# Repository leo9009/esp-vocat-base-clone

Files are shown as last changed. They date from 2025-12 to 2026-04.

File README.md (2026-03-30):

# ESP-VoCat Smart Rotating Base

English | [简体中文](README_CN.md)

## Project Overview

The ESP-VoCat rotating base is a smart rotating platform designed specifically for the [**ESP-VoCat development kit**](https://docs.espressif.com/projects/esp-dev-kits/zh_CN/latest/esp32s3/esp-vocat/user_guide_v1.2.html), tailored for toys, smart speakers, smart hubs, and other products requiring large language model voice interaction capabilities. The device uses the ESP32-C61-WROOM-1 module, supports USB Type-C power supply, and can power the ESP-VoCat main unit through a magnetic interface.

This project implements **high-precision stepper motor control, magnetic slide switch event detection, CSI sensing capabilities**, and stable **UART communication** as core functions. It can automatically adjust direction based on ESP-VoCat's **Sound Source Localization** results, enabling intelligent rotation toward sound sources. By combining motion control with sound source perception, it provides a more **natural and immersive** human-computer interaction experience.

## Key Features

- **Precise Angle Control** - High-precision rotational positioning based on stepper motor
- **Magnetic Slide Switch** - Multiple sensor support with automatic calibration
- **Rich Preset Actions** - Natural movements like shake head, look around, beat rhythm
- **Auto Homing** - Automatic zero position finding and calibration on startup
- **Bidirectional Communication** - Real-time data exchange between controller and base
- **Data Persistence** - Calibration data saved, survives power loss

## Project Structure

```
esp-vocat-base/
├── hardware/                    # Hardware design files
│   ├── schematics/              # Schematics
│   └── pcb/                     # PCB design files
├── software/                    # Firmware code
│   ├── common_components/       # Shared components for all examples
│   │   ├── stepper_motor/               # Stepper motor control
│   │   ├── magnetic_slide_switch/       # Magnetic switch (profile-based)
│   │   ├── control_serial/              # Serial communication
│   │   └── BMM150_SensorAPI/            # Sensor driver
│   ├── esp_vocat_rotating_base/                         # Base firmware
│   ├── esp_vocat_rotating_base_bell_event_detection/    # Bell slider event demo
│   ├── esp_vocat_rotating_base_iphone_detection/        # iPhone detection demo
│   └── esp_vocat_rotating_base_magnetic_accessory_detection/ # Accessory detection demo
├── README.md                    # English documentation
└── README_CN.md                 # Chinese documentation
```

## Example Projects

To avoid frequent branch switching, `software/` includes 4 independently buildable example projects:

- `esp_vocat_rotating_base`  
  Base firmware with standard capabilities: stepper actions, core magnetic slider events, UART communication, calibration, and status sync.

- `esp_vocat_rotating_base_bell_event_detection`  
  Bell slider event detection demo, focused on bell-related magnetic slider event logic.

- `esp_vocat_rotating_base_iphone_detection`  
  iPhone detection demo, focused on phone approach/leave and under-base related detection events.

- `esp_vocat_rotating_base_magnetic_accessory_detection`  
  Magnetic accessory detection demo, focused on accessory magnetic event recognition (e.g. fish/ice-cream/donut style accessories).

All projects share common components under `software/common_components/`.  
The `magnetic_slide_switch` component selects different profiles per project to keep event definitions and detection behavior compatible.

## **Feature Showcase**

[**Video Showcase**](https://www.bilibili.com/video/BV19gSEBwEoj/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)

The ESP-VoCat base uses Espressif's **ESP32-C61-WROOM-1(N8R2)** module and communicates with the ESP-VoCat main unit via a custom UART protocol. In terms of mechanical structure, the base is equipped with a 24BYJ48 stepper motor, enabling sound source localization and various predefined rotation actions to enhance interaction experience.
Additionally, the ESP-VoCat base features a magnetic slide switch that unlocks more interactive experiences.

### **Sound Source Localization**
ESP-VoCat supports sound source localization, capable of real-time detection of sound direction and position in the environment. The system collects sound signals through a microphone array and analyzes sound intensity, phase, and other information to determine the azimuth of the sound source. Combined with an ultra-quiet stepper motor-based rotating base, it enables intelligent interaction facing the sound source.

Sound Source Localization

### **Multiple Preset Actions**
The rotating base supports various predefined actions:

- **Shake Head Action**
The shake head action makes the base gently swing the companion left and right, simulating a cat's curious or subtle gesture.

Shake Head

- **Curious Look Around**
The curious look around action makes the base move the companion's head left and right, with small random offsets, simulating a **cat naturally observing its environment**.

Look Around

- **Beat Rhythm**
The beat rhythm action enables ESP-VoCat to swing its head left and right according to **drum beats** in external music, creating an **interactive effect** synchronized with music.

Beat Following

- **Gentle Nuzzle**
The gentle nuzzle simulates a cat's tender nuzzling action: the base slowly turns left and returns to center, repeating several times. The motion is smooth and natural, with each pause enhancing the **tactile feel** and **gentleness**.

Nuzzle

  **Notes:**
  All actions are **parametrically controllable**, facilitating integration with large models like **Doubao** and **Xiaozhi**.
  To better execute actions, the base's motor control features:
  - **Precise Angle Control:** Supports rotation at any angle with precision up to 0.1 degrees, serving sound source localization
  - **Smooth Acceleration/Deceleration:** Uses acceleration algorithms for natural and smooth rotation
  - **Auto Homing Calibration:** 
  Since the ESP-VoCat rotating base is driven by a stepper motor, it has no angle feedback. Therefore, the base performs zero position calibration at startup:
   1. After power-on, the motor automatically rotates left to find the limit switch
   2. After touching the limit switch, the motor rotates right 95° to the center position
   3. After calibration is complete, the motor powers off

### **Magnetic Slide Switch Interaction Control**
The ESP-VoCat base implements multiple interaction controls through a **magnetic** slide switch. Different slider positions change the magnetic field strength around the magnetometer. The base identifies slider actions by monitoring these magnetic field changes in real-time. When position changes are detected, the base reports corresponding events to ESP-VoCat via serial port, enabling rich and intuitive interactive experiences.

Supports 9 types of magnetic slide switch event detection:
   - Slider moved from up to down (`SLIDE_DOWN`): Slider is moved from the upper position to the lower position.
   - Slider moved from down to up (`SLIDE_UP`): Slider is moved from the lower position to the upper position.
   - Slider removed from up position (`REMOVE_FROM_UP`): Slider is removed from the upper position.
   - Slider removed from down position (`REMOVE_FROM_DOWN`): Slider is removed from the lower position.
   - Slider placed at up position (`PLACE_FROM_UP`): Slider is placed into the upper position.
   - Slider placed at down position (`PLACE_FROM_DOWN`): Slider is placed into the lower position.
   - Single click action (`SINGLE_CLICK`): A single-click action is detected when the slider stays at the lower position.
   - Fish feeding event (`FISH_ATTACHED`): Fish accessory is detected as attached.
   - Pairing mode (`PAIRING`): Two ESP-VoCat devices are face-to-face and pairing condition is detected.

Magnetic Switch

Magnetic slide switch control supports **multiple sensors**:
 - BMM150 3-axis magnetometer
 - QMC6309 3-axis magnetometer
 - Linear Hall sensor

  **Notes:**
  1. **Choose one** of the above sensors; **BMM150** is selected by default. When using a linear Hall sensor, **only** slider up/down sliding (SLIDE_UP / SLIDE_DOWN) event detection is supported!
  2. Before first use, **fully automatic calibration** of the magnetic slide switch is required to adapt to the magnetic environment, recording magnetic field strength baseline values for three states: **up / down / removed**:
     - System automatically detects three stable positions (keep still for about 500ms each position)
     - No manual prompts required, system automatically judges position differences
     - Calibration data persistently stored via NVS Flash, survives power loss
     - During use, recalibration can be triggered by sending a serial command from ESP-VoCat or long-pressing the base's Boot button

Based on magnetometer detection results combined with intelligent motion determination algorithms, the base can recognize nine types of actions and events.

### **CSI Sensing Capability**
The companion can perceive environmental changes through Wi-Fi CSI (Channel State Information), enabling action triggering or environmental interaction.
- **Movement Detection** 
By obtaining CSI information from routers through the companion, human movement throughout the entire space can be detected, enabling human movement detection and data statistics.

- **Near-field Perception** 
Through packet exchange between the companion and base, Wi-Fi transmission paths can be controlled to achieve small-range, high-precision detection. For example, when a human finger is detected approaching, the base can automatically adjust posture or execute preset actions, enabling smarter interactive experiences.

CSI Sensing

### **Serial Communication**
The ESP-VoCat rotating base communicates with ESP-VoCat via **UART protocol**.

- **Command Types**:
    - Angle control command (CMD_BASE_ANGLE_CONTROL)
    - Preset action control command (CMD_BASE_ACTION_CONTROL)
    - Preset action completion notification (CMD_ACTION_COMPLETE)
    - Magnetic switch event report (CMD_MAGNETIC_SWITCH_EVENT)
    - Magnetic data calibration progress sync (MAG_SWITCH_CALIB_*)

Note: Currently only the above basic command types are available; CSI-related commands will be added later.
    
-  **Data Frame Format**:
    -   `AA 55 [LEN_H] [LEN_L] [CMD] [DATA...] [CHECKSUM]` 
-  **Verification Mechanism**:
    - **Frame header** verification
    - **Checksum** verification

[**Detailed command data frame example**](software/esp_vocat_rotating_base/README.md)

## **Hardware Requirements**

### **Main Control Chip**
- **ESP32-C61-WROOM-1** or **ESP32-C61-WROOM-1U** module

ESP32-C61-WROOM-1 is used by default

- [**Hardware Open Source**](https://oshwhub.com/esp-college/esp-echoear-base)

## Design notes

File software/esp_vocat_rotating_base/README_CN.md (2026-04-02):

# ESP-VoCat-Base: 喵伴旋转底座

**中文** | [English](README.md)

## 项目简介

该项目工程是乐鑫"喵伴"智能交互设备的旋转底座固件，基于 ESP32-C61 芯片开发。该项目实现了步进电机精确控制、磁吸滑动开关检测、串口通信等功能，为智能设备提供生动的交互动作和灵敏的输入检测。

## 主要特性

### 步进电机控制
- **多种预定义动作**：
  - 摇头动作（固定幅度/渐变递减）
  - 左顾右盼观察动作
  - 猫咪蹭手动作
  - 跟随鼓点左右摆头动作

所有动作都可参数化调控，便于对接豆包、小智等大模型。
- **精确角度控制**：支持任意角度旋转，精度可达 0.1 度
- **平滑加减速**：采用加减速算法，运动更自然流畅
- **半步驱动模式**：提高精度 2 倍，运动更平滑
- **自动归位校准**：启动时通过限位开关自动回零

### 磁吸滑动开关
- **多种传感器支持**：
  - BMM150 三轴地磁传感器
  - QMC6309 三轴地磁传感器
  - 线性霍尔传感器

以上三种传感器三选一即可，默认选择 BMM150。
- **丰富的事件检测**：
  - 滑块上下滑动（SLIDE_UP / SLIDE_DOWN）
  - 从上/下位置取下（REMOVE_FROM_UP / REMOVE_FROM_DOWN）
  - 从上/下位置放回（PLACE_FROM_UP / PLACE_FROM_DOWN）
  - 单击事件（SINGLE_CLICK）：基于 mag_x 轴数据变化检测，结合 mag_x 和 mag_y 关系判断，防止滑动误触发
  - 喂鱼事件（FISH_ATTACHED）：检测小鱼从上位置放置的特定磁场变化
  - 配对模式（PAIRING）：检测长时间处于特定磁场状态
- **智能校准功能**：
  - 全自动校准流程：无需手动操作提示，系统自动检测三个稳定位置
  - 快速稳定检测：500ms 稳定时间（BMM150）/ 2000ms（QMC6309）
  - 智能位置识别：自动判断位置差异，避免重复记录
  - 校准数据持久化存储（NVS Flash）
  - 支持串口命令触发重新校准
  - 支持长按 Boot 键触发重新校准
  - 自动适配不同磁场环境

### 串口通信
- **UART 协议通信**：与 ESP-VoCat 进行数据通信
- **命令类型**：
  - 角度控制命令（CMD_BASE_ANGLE_CONTROL）
  - 预设动作控制命令（CMD_BASE_ACTION_CONTROL）
  - 预设动作完成通知（CMD_ACTION_COMPLETE）
  - 磁吸开关事件上报（CMD_MAGNETIC_SWITCH_EVENT）
  - 校准进度通知（MAG_SWITCH_CALIB_*）
- **数据帧格式**：`AA 55 [LEN_H] [LEN_L] [CMD] [DATA...] [CHECKSUM]`
- **校验机制**：支持**帧头**校验、**校验和**验证

## 硬件要求

### 主控芯片
- **ESP32-C61-WROOM-1** 或 **ESP32-C61-WROOM-1U** 模组

默认使用 ESP32-C61-WROOM-1

### 外设连接与引脚分配

#### 步进电机（28BYJ-48 + ULN2003 驱动 IC）
- IN1 → GPIO28
- IN2 → GPIO27
- IN3 → GPIO26
- IN4 → GPIO25

#### 磁力计传感器（I2C）
- SCL → GPIO3
- SDA → GPIO2
- 支持 BMM150（I2C 地址：0x10）
- 支持 QMC6309（I2C 地址：0x7C）

#### 线性霍尔传感器（ADC）
- ADC_PIN → GPIO5（ADC_CHANNEL_3）

#### 转台回零校准限位开关
- 回零校准限位开关检测引脚 → GPIO1（低电平有效）

#### BOOT 按键
- BOOT 按键 → GPIO9（低电平有效）

默认用于长按进行磁吸滑动开关校准。

#### UART 通信
- TXD → GPIO29
- RXD → GPIO8
- 波特率：115200

## 软件架构

### 主要组件

#### 1. stepper_motor（步进电机控制）
- 实现半步驱动控制算法
- 提供加减速曲线
- 封装多种预定义动作
- 支持精确角度旋转

#### 2. magnetic_slide_switch（磁吸滑动开关）
- 滑动窗口滤波算法（mag_z 轴）
- 状态机实现事件检测
- 单击检测（基于 mag_x 轴变化 + mag_x/mag_y 关系判断）
- 喂鱼事件检测（特定磁场增量范围）
- 配对模式检测（两个 ESP-VoCat 面对面靠近，用于配对联网）
- 全自动校准流程（时间基准 + 智能位置识别）
- 校准数据 NVS 持久化存储

#### 3. control_serial（串口通信）
- UART 收发任务
- 协议帧解析
- 命令分发处理
- 事件上报

#### 4. BMM150_SensorAPI（传感器驱动）
- BMM150 官方 API 适配
- I2C 总线封装

### 任务结构
```
app_main
├── base_calibration_task          // 底座角度校准任务（启动时，完成后销毁）
├── uart_cmd_receive_task          // UART 命令接收任务
├── magnetic_detect_task           // 磁吸附状态周期上报任务
├── magnetometer_calibration_task  // 磁吸开关自动校准任务
└── slide_switch_event_detect_task // 磁吸滑动开关事件检测任务
```

## 快速开始

### 环境准备

1. **ESP-IDF 版本**

- ESP-IDF release/v5.5(v5.5-445-g1191f4c4f91-dirty)

### 配置项目

使用 `idf.py menuconfig` 选择磁吸滑动开关所用的传感器：

 `Component config → Magnetic Slide Switch → Sensor Type`

选择传感器类型：BMM150 / QMC6309 / Linear Hall Sensor

### 编译烧录

```bash
# 编译项目
idf.py build
# 烧录固件
idf.py flash
# 查看日志
idf.py monitor
```

## 使用说明

### 首次启动

1. **底座角度校准**：
   - 上电后，电机会自动向左旋转寻找限位开关
   - 触碰到限位开关后，电机会向右旋转 95° 到中心位置
   - 校准完成后，电机断电

2. **磁吸开关自动校准**（如果是首次使用）：
   - 系统自动检测第一个稳定位置（保持滑块静止约 500ms）
   - 系统记录第一个位置后，提示：`First position calibrated`
   - 将滑块移动到第二个不同位置（上/下/拿掉），系统自动检测稳定
   - 系统记录第二个位置后，发送 `0x12` 给 ESP-VoCat，通知第二个位置校准完成
   - 将滑块移动到第三个不同位置，系统自动检测稳定
   - 系统记录第三个位置后，自动按磁场强度排序分配到 REMOVED/UP/DOWN
   - 校准完成后发送 `0x13` 给 ESP-VoCat，通知校准完毕
   - 校准数据自动保存到 Flash，下次启动自动加载
   
   **注意**：
   - 每个位置需要保持静止，等待系统自动检测稳定（约 500ms）
   - 三个位置的磁场差异需大于 100（系统自动判断）
   - 移动过程中数据变化正常，系统会自动等待稳定后记录

### 重新校准

**方法 1：长按 Boot 按键**
- 长按 GPIO9 的 Boot 按键（约 1.5 秒）
- 系统自动进入重新校准模式

**方法 2：串口命令**
- 发送命令：`AA 55 00 03 03 00 10 13`
- 系统收到命令后进入重新校准模式

### 串口命令

#### 1. 磁吸通知命令（0x00）
`
AA 55 00 03 00 00 01 01
`

底座会周期性发送该命令，ESP-VoCat 在被磁吸连接后若成功接收到此命令，即可确认已与底座建立连接，并开始播放连接动画。

#### 2. 角度控制命令（0x01）
**格式**：`AA 55 00 03 01 [ANGLE_H] [ANGLE_L] [CHECKSUM]`

**示例**：旋转到 45°
```
AA 55 00 03 01 00 2D 2E
```
- `00 2D` = 45（十进制）
- `2E` = `01 + 00 + 2D`（校验和）

#### 3. 动作控制命令（0x02）
**格式**：`AA 55 00 03 02 00 [ACTION] [CHECKSUM]`

**动作码**：
- `0x01`：摇头（SHAKE_HEAD）
- `0x02`：左顾右盼（LOOK_AROUND）
- `0x03`：跟随鼓点-鼓类（BEAT_SWING_DRUM）
- `0x04`：猫咪蹭手（CAT_NUZZLE）
- `0x05`：跟随鼓点-其他乐器（BEAT_SWING_OTHER）

**示例**：执行左顾右盼动作
```
AA 55 00 03 02 00 02 04
```

#### 4. 磁吸开关事件上报（0x03）
**格式**：`AA 55 00 03 03 00 [EVENT] [CHECKSUM]`

**事件码**：
- `0x01`：滑块向下滑动（SLIDE_DOWN）
- `0x02`：滑块向上滑动（SLIDE_UP）
- `0x03`：从上面拿下（REMOVE_FROM_UP）
- `0x04`：从下面拿下（REMOVE_FROM_DOWN）
- `0x05`：从上面放回（PLACE_FROM_UP）
- `0x06`：从下面放回（PLACE_FROM_DOWN）
- `0x07`：单击事件（SINGLE_CLICK）
- `0x08`：喂鱼事件（FISH_ATTACHED）- 小鱼从上位置放置时触发
- `0x09`：配对模式（PAIRING）- 长时间处于特定磁场状态
- `0x10`：启动数据校准程序
- `0x11`：校准开始通知
- `0x12`：第二个位置校准完成（头部收到后语音提示第三步）
- `0x13`：校准完成

#### 5. 动作完成通知（0x02）
**格式**：`AA 55 00 03 02 00 10 12`

- 底座在执行完任意特定动作后自动发送
- 头部可根据此命令同步状态

## 步进电机动作详解

### 1. stepper_shake_head（摇头）
```c
stepper_shake_head(float amplitude, int cycles, int speed_us);
```
- `amplitude`：摆动幅度（度）
- `cycles`：摆动次数
- `speed_us`：速度（微秒/步）

### 2. stepper_shake_head_decay（渐变摇头）
```c
stepper_shake_head_decay(float initial_amplitude, float decay_rate, int speed_us);
```
- `initial_amplitude`：初始幅度（度）
- `decay_rate`：衰减系数（0.0-1.0，如 0.8 表示每次衰减 20%）
- `speed_us`：速度（微秒/步）

### 3. stepper_look_around（左顾右盼）
```c
stepper_look_around(float left_angle, float right_angle, float scan_angle, 
                    int pause_ms, int large_speed_us, int small_speed_us);
```
- `left_angle`：左侧最大角度
- `right_angle`：右侧最大角度
- `scan_angle`：小幅度扫视角度
- `pause_ms`：每次转动后的停顿时间
- `large_speed_us`：大幅度转动速度
- `small_speed_us`：小幅度扫视速度

### 4. stepper_cat_nuzzle（猫咪蹭手）
```c
stepper_cat_nuzzle(float angle, int cycles, int speed_us);
```
- `angle`：蹭动幅度（度）
- `cycles`：蹭动次数
- `speed_us`：速度（微秒/步）

### 5. stepper_beat_swing（跟随鼓点）
```c
stepper_beat_swing(float angle, int speed_us);
```
- `angle`：摆动角度（度）
- `speed_us`：速度（微秒/步）
- **智能摆动逻辑**：
  - 同类乐器连续触发 → 向另一侧摆动 15 度

## 磁吸开关校准原理

### 自动校准流程状态机

```
CALIBRATION_DETECTING_FIRST      // 自动检测第一个稳定位置
         ↓                       // 数据稳定 500ms 后自动记录
CALIBRATION_WAITING_CHANGE_1     // 等待数据变化（用户移动滑块）
         ↓                       // 检测到变化量 > 100
CALIBRATION_DETECTING_SECOND     // 自动检测第二个稳定位置
         ↓                       // 数据稳定 500ms 后自动记录
         |                       // （发送 0x12 通知头部）
CALIBRATION_WAITING_CHANGE_2     // 等待数据变化（用户移动滑块）
         ↓                       // 检测到变化量 > 100
CALIBRATION_DETECTING_THIRD      // 自动检测第三个稳定位置
         ↓                       // 数据稳定 500ms 后自动记录
CALIBRATION_COMPLETED            // 自动排序并保存到 Flash
                                 // （发送 0x13 通知头部）
```

### 关键技术点

1. **滑动窗口滤波**：5 点滑动平均，降低噪声干扰
2. **时间基准稳定性检测**：
   - 使用系统时钟（FreeRTOS Tick）精确计时
   - 数据变化小于 10 个单位视为稳定
   - BMM150：连续稳定 500ms 后记录
   - QMC6309：连续稳定 500ms 后记录
3. **智能位置识别**：
   - 自动检测数据变化量（阈值 100）
   - 新位置必须与已记录位置差异明显
   - 防止重复记录同一位置
4. **自动排序分配**：
   - 按磁场强度从小到大排序
   - 最小值 → REMOVED（拿掉）
   - 中间值 → UP（上位置）
   - 最大值 → DOWN（下位置）
5. **NVS 持久化**：校准数据保存到 Flash，掉电不丢失
6. **无需手动提示**：全程自动检测，用户只需按顺序移动滑块并保持静止

### 磁场值参考范围（BMM150）
- **REMOVED**（拿掉）：~700-800（默认 709）
- **UP**（上位置）：~1300-1400（默认 1383）
- **DOWN**（下位置）：~2000-2100（默认 2047）
- **FISH_ATTACHED**（喂鱼）：REMOVED + 150~200

*注：实际值因磁铁强度和安装位置而异，自动校准会根据实际磁场分配位置*

### 事件检测特点

**单击事件检测**：
- 基于 mag_x 轴数据变化（drop/rise threshold: 100）
- 结合 mag_x 和 mag_y 大小关系判断滑块位置
- 仅在滑块处于 DOWN 位置时检测（mag_x > mag_y）
- 持续时间过滤：< 300ms 为有效单击
- 防止快速滑动误触发

**喂鱼事件检测**：
- 仅在 REMOVED 位置后检测
- 磁场增量在 150-200 范围内
- 区别于 PLACE_FROM_UP（增量更大，接近 UP_CENTER）

**配对模式检测**：
- REMOVED 位置后磁场继续下降
- 下降量 > 100（BMM150）/ 150（QMC6309）
- 稳定保持该状态

### 常见问题

**Q1：电机抖动或不转**
- 检查供电是否充足（至少 5V 1A）
- 检查接线是否正确
- 尝试降低速度（增大 `speed_us` 参数）

**Q2：磁吸开关校准失败**
- 确保传感器 I2C 连接正常
- 检查传感器类型配置是否匹配
- 每个位置需保持静止至少 500ms（BMM150）/ 2000ms（QMC6309）
- 三个位置的磁场差异需大于 100，确保位置明确不同
- 如移动过快导致检测不到变化，可稍等片刻让系统重新检测

**Q3：单击事件误触发或不触发**
- 误触发：可能是快速滑动导致，系统已通过 mag_x/mag_y 关系优化
- 不触发：确保滑块在 DOWN 位置（mag_x > mag_y），单击动作要明确快速
- 单击时长应小于 300ms，过慢会被识别为滑动

**Q4：串口通信异常**
- 检查波特率是否为 115200
- 确认 TX/RX 接线是否正确
- 检查校验和是否计算正确

**Q5：首次上电电机旋转方向错误**
- 检查限位开关安装位置
- 调整 `base_calibration_task` 中的旋转角度

## 性能参数

- **角度控制精度**：±0.5°
- **最快旋转速度**：600 μs/步（约 200°/秒）
- **磁吸开关响应时间**：< 50ms
- **磁吸开关采样率**：100 Hz（BMM150，10ms 周期）/ 500 Hz（QMC6309，2ms 周期）
- **校准稳定检测时间**：500ms（BMM150）/ 2000ms（QMC6309）
- **单击检测时间窗口**：< 300ms（BMM150）/ < 250ms（QMC6309）
- **串口通信速率**：115200 bps
- **内存占用**：~80KB RAM，~200KB Flash

## 版本历史

### v1.1.0
- **新增功能**：
  - 喂鱼事件检测（FISH_ATTACHED）
  - 配对模式检测（PAIRING）
- **优化改进**：
  - 磁吸数据校准流程全自动化（无需手动提示）
  - 时间基准稳定性检测（FreeRTOS Tick 计时）
  - 单击事件检测优化：基于 mag_x 轴 + mag_x/mag_y 关系判断
  - 防止快速滑动误触发单击事件
  - 校准稳定时间优化：BMM150 降至 500ms
  - 智能位置识别（自动判断位置差异）

### v1.0.0
- 步进电机基础控制
- 多种预定义动作
- 磁吸滑动开关事件检测
- 自动校准功能
- NVS 数据持久化
- 串口通信协议
- 智能跟随鼓点算法
- 长按 Boot 键重新校准
- 校准过程串口通信

## 许可证

本项目遵循 GPL 3.0 许可证。

---

**注意**：本项目为乐鑫"喵伴"智能设备配套固件，仅供学习和参考使用。

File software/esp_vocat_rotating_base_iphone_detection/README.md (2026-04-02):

# ESP-ESP-VoCat Rotating Base

[中文](README_CN.md) | **English**

## Project Introduction

This project is the firmware for the rotating base of Espressif's ESP-VoCat intelligent interactive device, developed based on the ESP32-C61 chip. The project implements precise stepper motor control, magnetic slide switch detection, UART communication, and other features, providing vivid interactive actions and sensitive input detection for smart devices.

## Main Features

### Stepper Motor Control
- **Multiple Predefined Actions**:
  - Head shaking action (fixed amplitude/gradual decay)
  - Look around observation action
  - Cat nuzzle action
  - Beat swing action following rhythm

All actions are parameterizable for easy integration with LLMs like Doubao and Xiaozhi.
- **Precise Angle Control**: Supports arbitrary angle rotation with precision up to 0.1 degrees
- **Smooth Acceleration/Deceleration**: Uses acceleration/deceleration algorithms for more natural and fluid motion
- **Half-Step Drive Mode**: Doubles precision for smoother movement
- **Auto Homing Calibration**: Automatically returns to zero position via limit switch on startup

### Magnetic Slide Switch
- **Multiple Sensor Support**:
  - BMM150 3-axis magnetometer
  - QMC6309 3-axis magnetometer
  - Linear Hall sensor

Choose one of the above three sensors, BMM150 is selected by default.
- **Rich Event Detection**:
  - Slider up/down sliding (SLIDE_UP / SLIDE_DOWN)
  - Remove from up/down position (REMOVE_FROM_UP / REMOVE_FROM_DOWN)
  - Place back from up/down position (PLACE_FROM_UP / PLACE_FROM_DOWN)
  - Single click event (SINGLE_CLICK): Detected based on mag_x axis data changes, combined with mag_x and mag_y relationship judgment to prevent false triggers from sliding
  - Fish feeding event (FISH_ATTACHED): Detects specific magnetic field changes when small fish is placed from up position
  - Pairing mode (PAIRING): Two ESP-VoCat devices face-to-face for pairing and networking
- **Smart Calibration Function**:
  - Fully automatic calibration process: No manual prompts required, system automatically detects three stable positions
  - Fast stability detection: 500ms stability time for both BMM150 and QMC6309
  - Intelligent position recognition: Automatically judges position differences to avoid duplicate recording
  - Calibration data persistent storage (NVS Flash)
  - Support UART command triggered recalibration
  - Support long press Boot button triggered recalibration
  - Auto-adapt to different magnetic field environments

### UART Communication
- **UART Protocol Communication**: Data communication with ESP-VoCat
- **Command Types**:
  - Angle control command (CMD_BASE_ANGLE_CONTROL)
  - Preset action control command (CMD_BASE_ACTION_CONTROL)
  - Preset action completion notification (CMD_ACTION_COMPLETE)
  - Magnetic switch event reporting (CMD_MAGNETIC_SWITCH_EVENT)
  - Calibration progress notification (MAG_SWITCH_CALIB_*)
- **Data Frame Format**: `AA 55 [LEN_H] [LEN_L] [CMD] [DATA...] [CHECKSUM]`
- **Verification Mechanism**: Supports **frame header** verification and **checksum** validation

## Hardware Requirements

### Main Control Chip
- **ESP32-C61-WROOM-1** or **ESP32-C61-WROOM-1U** module

ESP32-C61-WROOM-1 is used by default

### Peripheral Connection and Pin Assignment

#### Stepper Motor (28BYJ-48 + ULN2003 Driver IC)
- IN1 → GPIO28
- IN2 → GPIO27
- IN3 → GPIO26
- IN4 → GPIO25

#### Magnetometer Sensor (I2C)
- SCL → GPIO3
- SDA → GPIO2
- Supports BMM150 (I2C address: 0x10)
- Supports QMC6309 (I2C address: 0x7C)

#### Linear Hall Sensor (ADC)
- ADC_PIN → GPIO5 (ADC_CHANNEL_3)

#### Turntable Homing Calibration Limit Switch
- Homing calibration limit switch detection pin → GPIO1 (active low)

#### BOOT Button
- BOOT button → GPIO9 (active low)

Used by default for long press to trigger magnetic slide switch calibration.

#### UART Communication
- TXD → GPIO29
- RXD → GPIO8
- Baud rate: 115200

## Software Architecture

### Main Components

#### 1. stepper_motor (Stepper Motor Control)
- Implements half-step drive control algorithm
- Provides acceleration/deceleration curves
- Encapsulates multiple predefined actions
- Supports precise angle rotation

#### 2. magnetic_slide_switch (Magnetic Slide Switch)
- Sliding window filtering algorithm (mag_z axis)
- State machine implements event detection
- Single click detection (based on mag_x axis change + mag_x/mag_y relationship judgment)
- Fish feeding event detection (specific magnetic field increment range)
- Pairing mode detection (two ESP-VoCat face-to-face for pairing)
- Fully automatic calibration process (time-based + intelligent position recognition)
- Calibration data NVS persistent storage

#### 3. control_serial (UART Communication)
- UART TX/RX tasks
- Protocol frame parsing
- Command dispatch processing
- Event reporting

#### 4. BMM150_SensorAPI (Sensor Driver)
- BMM150 official API adaptation
- I2C bus encapsulation

### Task Structure
```
app_main
├── base_calibration_task          // Base angle calibration task (on startup)
├── uart_cmd_receive_task          // UART command receive task
├── uart_cmd_send_task             // UART command send task
├── magnetometer_data_read_task    // Magnetometer data read task (shared data source)
├── magnetometer_calibration_task  // Magnetic switch automatic calibration task
└── slide_switch_event_detect_task // Magnetic slide switch event detection task
```

## Quick Start

### Environment Preparation

1. **ESP-IDF Version**

- ESP-IDF release/v5.5(v5.5-445-g1191f4c4f91-dirty)

### Project Configuration

Use `idf.py menuconfig` to select the sensor for the magnetic slide switch:

 `Component config → Magnetic Slide Switch → Sensor Type`

Select sensor type: BMM150 / QMC6309 / Linear Hall Sensor

### Build and Flash

```bash
# Build project
idf.py build
# Flash firmware
idf.py flash
# View logs
idf.py monitor
```

## Usage Instructions

### First Startup

1. **Base Angle Calibration**:
   - After power-on, the motor will automatically rotate left to find the limit switch
   - After touching the limit switch, the motor will rotate right 95° to the center position
   - After calibration is complete, the motor powers off

2. **Magnetic Switch Automatic Calibration** (if first use):
   - System automatically detects the first stable position (keep slider still for about 500ms)
   - After the system records the first position, prompt: `First position calibrated`
   - Move the slider to a second different position (up/down/removed), system automatically detects stability
   - After the system records the second position, send `0x12` to ESP-VoCat to notify second position calibration complete
   - Move the slider to a third different position, system automatically detects stability
   - After the system records the third position, automatically sort by magnetic field strength and assign to REMOVED/UP/DOWN
   - After calibration is complete, send `0x13` to ESP-VoCat to notify calibration complete
   - Calibration data is automatically saved to Flash, automatically loaded on next startup
   
   **Note**:
   - Each position needs to be kept still for system to automatically detect stability (about 500ms)
   - The magnetic field difference between three positions must be greater than 100 (system automatically judges)
   - Data changes during movement are normal, system will automatically wait for stability before recording

### Recalibration

**Method 1: Long Press Boot Button**
- Long press the Boot button on GPIO9 (about 1.5 seconds)
- System automatically enters recalibration mode

**Method 2: UART Command**
- Send command: `AA 55 00 03 03 00 10 16`
- System enters recalibration mode after receiving the command

### UART Commands

#### 1. Magnetic Attachment Notification Command（0x00）
`
AA 55 00 03 00 00 01 01
`

The base periodically sends this command. Once ESP-VoCat is magnetically attached and successfully receives the command, it can confirm that the connection to the base has been established and then start playing the connection animation.

#### 2. Angle Control Command (0x01)
**Format**: `AA 55 00 03 01 [ANGLE_H] [ANGLE_L] [CHECKSUM]`

**Example**: Rotate to 45°
```
AA 55 00 03 01 00 2D 2E
```
- `00 2D` = 45 (decimal)
- `2E` = `01 + 00 + 2D` (checksum)

#### 3. Action Control Command (0x02)
**Format**: `AA 55 00 03 02 00 [ACTION] [CHECKSUM]`

**Action Codes**:
- `0x01`: Shake head (SHAKE_HEAD)
- `0x02`: Look around (LOOK_AROUND)
- `0x03`: Beat swing - drum (BEAT_SWING_DRUM)
- `0x04`: Cat nuzzle (CAT_NUZZLE)
- `0x05`: Beat swing - other instruments (BEAT_SWING_OTHER)

**Example**: Execute look around action
```
AA 55 00 03 02 00 02 04
```

#### 4. Magnetic Switch Event Reporting (0x03)
**Format**: `AA 55 00 03 03 00 [EVENT] [CHECKSUM]`

**Event Codes**:
- `0x01`: Slider slides down (SLIDE_DOWN)
- `0x02`: Slider slides up (SLIDE_UP)
- `0x03`: Remove from top (REMOVE_FROM_UP)
- `0x04`: Remove from bottom (REMOVE_FROM_DOWN)
- `0x05`: Place back from top (PLACE_FROM_UP)
- `0x06`: Place back from bottom (PLACE_FROM_DOWN)
- `0x07`: Single click event (SINGLE_CLICK)
- `0x08`: Fish feeding event (FISH_ATTACHED) - Triggered when small fish is placed from up position
- `0x09`: Pairing mode (PAIRING) - Two ESP-VoCat face-to-face for pairing
- `0x10`: Start calibration program
- `0x11`: Calibration start notification
- `0x12`: Second position calibration complete (ESP-VoCat gives voice prompt for third step after receiving)
- `0x13`: Calibration complete

#### 5. Action Completion Notification (0x02)
**Format**: `AA 55 00 03 02 00 10 12`

- Base automatically sends after completing any specific action
- ESP-VoCat can synchronize status according to this command

## Stepper Motor Action Details

### 1. stepper_shake_head (Shake Head)
```c
stepper_shake_head(float amplitude, int cycles, int speed_us);
```
- `amplitude`: Swing amplitude (degrees)
- `cycles`: Number of swings
- `speed_us`: Speed (microseconds/step)

### 2. stepper_shake_head_decay (Gradual Decay Shake Head)
```c
stepper_shake_head_decay(float initial_amplitude, float decay_rate, int speed_us);
```
- `initial_amplitude`: Initial amplitude (degrees)
- `decay_rate`: Decay coefficient (0.0-1.0, e.g., 0.8 means 20% decay each time)
- `speed_us`: Speed (microseconds/step)

### 3. stepper_look_around (Look Around)
```c
stepper_look_around(float left_angle, float right_angle, float scan_angle, 
                    int pause_ms, int large_speed_us, int small_speed_us);
```
- `left_angle`: Maximum left angle
- `right_angle`: Maximum right angle
- `scan_angle`: Small amplitude scan angle
- `pause_ms`: Pause time after each rotation
- `large_speed_us`: Large amplitude rotation speed
- `small_speed_us`: Small amplitude scan speed

### 4. stepper_cat_nuzzle (Cat Nuzzle)
```c
stepper_cat_nuzzle(float angle, int cycles, int speed_us);
```
- `angle`: Nuzzle amplitude (degrees)
- `cycles`: Number of nuzzles
- `speed_us`: Speed (microseconds/step)

### 5. stepper_beat_swing (Beat Swing)
```c
stepper_beat_swing(float angle, int speed_us);
```
- `angle`: Swing angle (degrees)
- `speed_us`: Speed (microseconds/step)
- **Smart Swing Logic**:
  - Same instrument type continuously triggered → Swing 15 degrees to the other side

## Magnetic Switch Calibration Principle

### Automatic Calibration Flow State Machine

```
CALIBRATION_DETECTING_FIRST      // Automatically detect first stable position
         ↓                       // Record automatically after data stable for 500ms
CALIBRATION_WAITING_CHANGE_1     // Wait for data change (user moves slider)
         ↓                       // Change amount detected > 100
CALIBRATION_DETECTING_SECOND     // Automatically detect second stable position
         ↓                       // Record automatically after data stable for 500ms
         |                       // (Send 0x12 to notify ESP-VoCat)
CALIBRATION_WAITING_CHANGE_2     // Wait for data change (user moves slider)
         ↓                       // Change amount detected > 100
CALIBRATION_DETECTING_THIRD      // Automatically detect third stable position
         ↓                       // Record automatically after data stable for 500ms
CALIBRATION_COMPLETED            // Auto sort and save to Flash
                                 // (Send 0x13 to notify ESP-VoCat)
```

### Key Technical Points

1. **Sliding Window Filtering**: 5-point moving average to reduce noise interference
2. **Time-based Stability Detection**:
   - Uses system clock (FreeRTOS Tick) for precise timing
   - Data change less than 10 units considered stable
   - Both BMM150 and QMC6309: Record after continuous stability for 500ms
3. **Intelligent Position Recognition**:
   - Automatically detects data change amount (threshold 100)
   - New position must be significantly different from recorded positions
   - Prevents duplicate recording of same position
4. **Automatic Sorting and Assignment**:
   - Sort by magnetic field strength from small to large
   - Smallest value → REMOVED (removed)
   - Middle value → UP (up position)
   - Largest value → DOWN (down position)
5. **NVS Persistence**: Calibration data saved to Flash, not lost after power off
6. **No Manual Prompts Required**: Fully automatic detection, users only need to move slider in sequence and keep still

### Magnetic Field Value Reference Range (BMM150)
- **REMOVED** (removed): ~700-800 (default 709)
- **UP** (up position): ~1300-1400 (default 1383)
- **DOWN** (down position): ~2000-2100 (default 2047)
- **FISH_ATTACHED** (fish feeding): REMOVED + 150~200

*Note: Actual values vary due to magnet strength and installation position, automatic calibration will assign positions based on actual magnetic field*

### Event Detection Features

**Single Click Event Detection**:
- Based on mag_x axis data change (drop/rise threshold: 100)
- Combined with mag_x and mag_y size relationship to judge slider position
- Only detected when slider is at DOWN position (mag_x > mag_y)
- Duration filtering: < 300ms for valid click
- Prevents false triggers from fast sliding

**Fish Feeding Event Detection**:
- Only detected after REMOVED position
- Magnetic field increment in 150-200 range
- Distinguished from PLACE_FROM_UP (larger increment, close to UP_CENTER)

**Pairing Mode Detection**:
- Magnetic field continues to drop after REMOVED position
- Drop amount > 100 (BMM150) / 150 (QMC6309)
- Stably maintains this state

### Common Issues

**Q1: Motor vibrates or doesn't rotate**
- Check if power supply is sufficient (at least 5V 1A)
- Check if wiring is correct
- Try reducing speed (increase `speed_us` parameter)

**Q2: Magnetic switch calibration fails**
- Ensure sensor I2C connection is normal
- Check if sensor type configuration matches
- Each position needs to be kept still for at least 500ms (both BMM150 and QMC6309)
- The magnetic field difference between three positions must be greater than 100, ensure positions are clearly different
- If movement is too fast causing detection failure, wait a moment for system to re-detect

**Q3: Single click event false trigger or not triggered**
- False trigger: May be caused by fast sliding, system has been optimized through mag_x/mag_y relationship
- Not triggered: Ensure slider is at DOWN position (mag_x > mag_y), click action should be clear and fast
- Click duration should be less than 300ms, too slow will be recognized as sliding

**Q4: UART communication abnormal**
- Check if baud rate is 115200
- Confirm TX/RX wiring is correct
- Check if checksum is calculated correctly

**Q5: Motor rotates in wrong direction on first power-on**
- Check limit switch installation position
- Adjust rotation angle in `base_calibration_task`

## Performance Parameters

- **Angle Control Precision**: ±0.5°
- **Fastest Rotation Speed**: 600 μs/step (about 200°/second)
- **Magnetic Switch Response Time**: < 50ms
- **Magnetic Switch Sampling Rate**: 100 Hz (BMM150, 10ms period) / 500 Hz (QMC6309, 2ms period)
- **Calibration Stability Detection Time**: 500ms (both BMM150 and QMC6309)
- **Single Click Detection Time Window**: < 300ms (BMM150) / < 250ms (QMC6309)
- **UART Communication Rate**: 115200 bps
- **Memory Usage**: ~80KB RAM, ~200KB Flash

## Version History

### v1.1.0
- **New Features**:
  - Fish feeding event detection (FISH_ATTACHED)
  - Pairing mode detection (PAIRING)
- **Optimizations**:
  - Fully automatic magnetic data calibration process (no manual prompts required)
  - Time-based stability detection (FreeRTOS Tick timing)
  - Single click event detection optimization: Based on mag_x axis + mag_x/mag_y relationship judgment
  - Prevents false single click triggers from fast sliding
  - Calibration stability time optimization: Both BMM150 and QMC6309 reduced to 500ms
  - Intelligent position recognition (automatically judges position differences)

### v1.0.0
- Stepper motor basic control
- Multiple predefined actions
- Magnetic slide switch event detection
- Auto calibration function
- NVS data persistence
- UART communication protocol
- Smart beat following algorithm
- Long press Boot button recalibration
- Calibration process UART communication

## License

This project follows the GPL 3.0 license.

---

**Note**: This project is supporting firmware for Espressif's ESP-VoCat smart device, for learning and reference only.

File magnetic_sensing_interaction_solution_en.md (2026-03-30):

# Magnetic Sensing Interaction Solution Introduction

[中文](./magnetic_sensing_interaction_solution_zh.md) | [English](./magnetic_sensing_interaction_solution_en.md)

## 1. Overview

The ESP-VoCat base uses a magnetic slide switch to provide rich interaction control. Different slider positions change the local magnetic field, and the firmware continuously samples sensor data to detect slider actions. Detected events are reported to ESP-VoCat via UART.

## 2. Event Types by Demo Project

### 2.1 Bell Slider Event Detection Demo
Project: [`software/esp_vocat_rotating_base_bell_event_detection`](./software/esp_vocat_rotating_base_bell_event_detection/)

Supported events:

- `SLIDE_DOWN`: Slider is moved from the upper position to the lower position.
- `SLIDE_UP`: Slider is moved from the lower position to the upper position.
- `REMOVE_FROM_UP`: Slider is removed from the upper position.
- `REMOVE_FROM_DOWN`: Slider is removed from the lower position.
- `PLACE_FROM_UP`: Slider is placed into the upper position.
- `PLACE_FROM_DOWN`: Slider is placed into the lower position.
- `SINGLE_CLICK`: A single-click action is detected when the slider stays at the lower position.

### 2.2 iPhone Detection Demo
Project: [`software/esp_vocat_rotating_base_iphone_detection`](./software/esp_vocat_rotating_base_iphone_detection/)

Supported events:

- `IPHONE_LEAN_FRONT`: iPhone leans against the front side of the base.
- `IPHONE_LEAN_FRONT_DETACHED`: iPhone leaves the front side of the base.
- `IPHONE_UNDER_BASE`: iPhone is placed under the base and enters a valid detected state.
- `IPHONE_UNDER_BASE_DETACHED`: iPhone is removed from under the base.

### 2.3 Magnetic Accessory Detection Demo
Project: [`software/esp_vocat_rotating_base_magnetic_accessory_detection`](./software/esp_vocat_rotating_base_magnetic_accessory_detection/)

Supported events:

- `FISH_ATTACHED`: Fish accessory is detected as attached.
- `FISH_DETACHED`: Fish accessory is removed from the base.
- `PAIRING`: Pairing condition is detected and pairing mode is entered.
- `PAIRING_CANCELLED`: Pairing condition disappears and pairing mode is exited.
- `ICE_CREAM_ATTACHED`: Ice-cream accessory is detected as attached.
- `ICE_CREAM_DETACHED`: Ice-cream accessory is removed from the base.
- `DONUT_ATTACHED`: Donut accessory is detected as attached.
- `DONUT_DETACHED`: Donut accessory is removed from the base.

> Note: Event sets are defined by the `magnetic_slide_switch` profile selected by each demo. The source code enum definition is the final reference.

## 3. Sensor Support

One of the following sensors can be used:

- BMM150 3-axis magnetometer (default)
- QMC6309 3-axis magnetometer
- Linear Hall sensor

## 4. Notes

1. Different demo projects expose different event sets. Switch project to switch behavior.
2. Run full auto-calibration before first use to capture baseline values for up/down/removed states.
3. Calibration data is persisted in NVS and survives power cycles.
4. Recalibration can be triggered by UART command or by long-pressing the base Boot button.

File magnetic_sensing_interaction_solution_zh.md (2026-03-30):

# 磁感应交互方案介绍

[中文](./magnetic_sensing_interaction_solution_zh.md) | [English](./magnetic_sensing_interaction_solution_en.md)

## 1. 功能概述

ESP-VoCat 底座通过磁吸式滑动开关实现多种交互控制。滑块不同位置会改变地磁传感器附近的磁场强度，系统通过持续采样与状态判定识别滑块动作，并将事件通过串口上报给 ESP-VoCat，实现更直观的交互体验。

## 2. 事件类型（按示例工程）

### 2.1 铃铛滑块事件检测示例
对应工程：[`software/esp_vocat_rotating_base_bell_event_detection`](./software/esp_vocat_rotating_base_bell_event_detection/)

支持事件：

- `SLIDE_DOWN`：滑块从上方拨到下方。
- `SLIDE_UP`：滑块从下方拨到上方。
- `REMOVE_FROM_UP`：滑块从上方位置被拿走。
- `REMOVE_FROM_DOWN`：滑块从下方位置被拿走。
- `PLACE_FROM_UP`：滑块被放置到上方位置。
- `PLACE_FROM_DOWN`：滑块被放置到下方位置。
- `SINGLE_CLICK`：滑块位于下方时触发一次单击动作。

### 2.2 手机检测示例
对应工程：[`software/esp_vocat_rotating_base_iphone_detection`](./software/esp_vocat_rotating_base_iphone_detection/)

支持事件：

- `IPHONE_LEAN_FRONT`：手机从底座正面倚靠上去。
- `IPHONE_LEAN_FRONT_DETACHED`：手机从底座正面离开。
- `IPHONE_UNDER_BASE`：手机被放到底座下方并进入有效检测状态。
- `IPHONE_UNDER_BASE_DETACHED`：手机从底座下方移开。

### 2.3 磁吸配件检测示例
对应工程：[`software/esp_vocat_rotating_base_magnetic_accessory_detection`](./software/esp_vocat_rotating_base_magnetic_accessory_detection/)

支持事件：

- `FISH_ATTACHED`：检测到喂鱼配件吸附。
- `FISH_DETACHED`：喂鱼配件从底座移除。
- `PAIRING`：检测到配对条件成立（进入配对状态）。
- `PAIRING_CANCELLED`：配对条件消失（退出配对状态）。
- `ICE_CREAM_ATTACHED`：检测到雪糕配件吸附。
- `ICE_CREAM_DETACHED`：雪糕配件从底座移除。
- `DONUT_ATTACHED`：检测到甜甜圈配件吸附。
- `DONUT_DETACHED`：甜甜圈配件从底座移除。

> 说明：以上事件来自三个示例工程对应的 `magnetic_slide_switch` profile 定义。实际以代码中的枚举为准。

## 3. 传感器支持

磁吸滑动开关支持以下传感器（三选一）：

- BMM150 三轴地磁传感器（默认）
- QMC6309 三轴地磁传感器
- 线性霍尔传感器

## 4. 使用注意事项

1. 不同示例工程事件集合不同，切换工程即可切换检测策略。
2. 首次使用前需执行全自动校准，记录上方 / 下方 / 移除三种状态的基准磁场值。
3. 校准数据会持久化保存至 NVS，掉电不丢失。
4. 运行中可通过串口命令或长按底座 Boot 键触发重新校准。

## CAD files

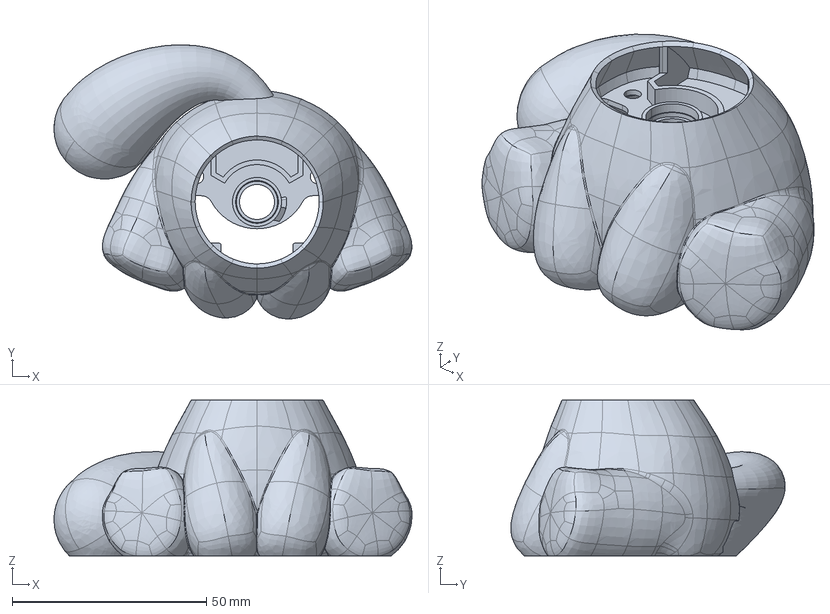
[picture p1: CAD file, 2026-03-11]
3D_models/ESP-VoCat_catbase_20251128.stp
92.0 x 70.5 x 40.0 mm

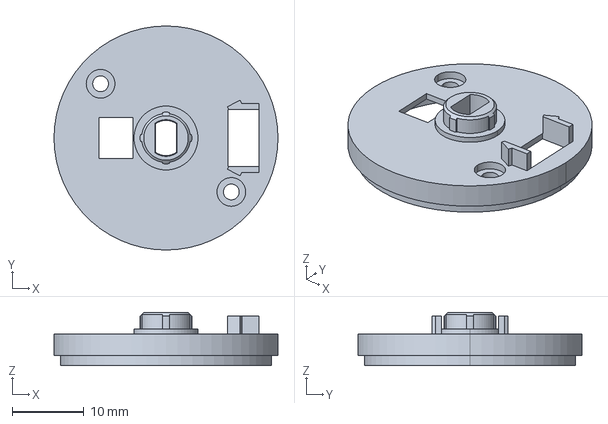
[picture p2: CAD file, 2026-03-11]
3D_models/ESP-VoCat_catbase_platform_btm_20251128.stp
31.2 x 31.2 x 7.40 mm

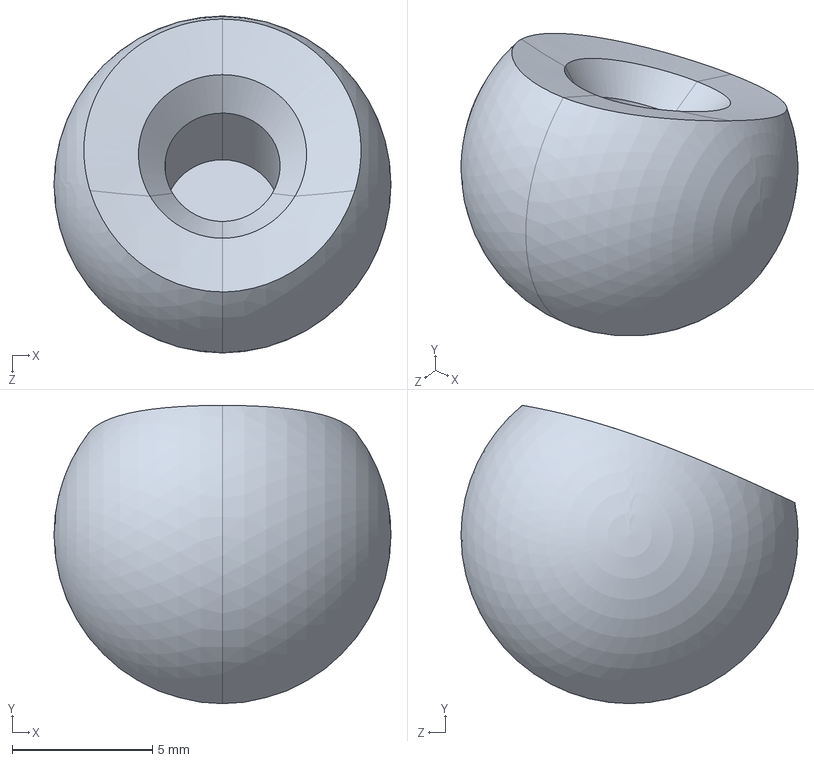
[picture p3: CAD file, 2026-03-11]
3D_models/ESP-VoCat catbase ball only 2025-11-22.STEP
12.0 x 10.6 x 12.0 mm

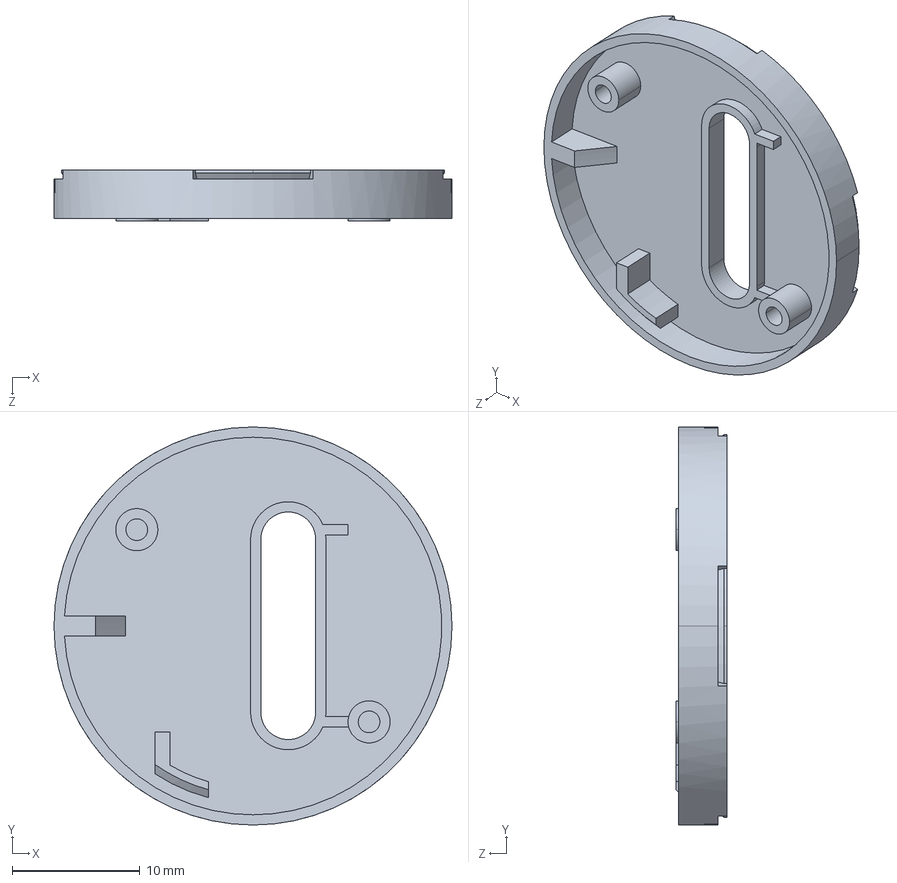
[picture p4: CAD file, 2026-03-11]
3D_models/ESP-VoCat catbase platform top 2025-11-22.STEP
31.2 x 31.2 x 4.00 mm

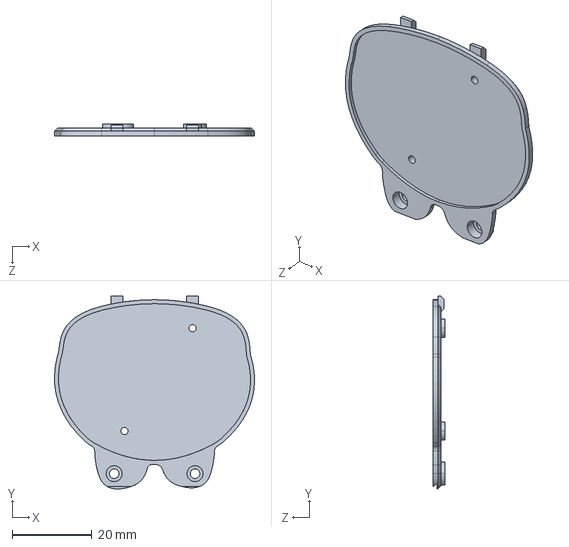
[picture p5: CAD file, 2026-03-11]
3D_models/ESP-VoCat catbase cover 2025-11-22.STEP
50.2 x 48.4 x 3.00 mm

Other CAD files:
3D_models/vocat catbase platform top 2025-11-22.STEP
3D_models/vocat catbase ball only 2025-11-22.STEP
3D_models/vocat catbase cover 2025-11-22.STEP
3D_models/vocat_catbase_platform_btm_20251128.stp
3D_models/VoCat_catbase_20251128.stp
3D_models/EchoEar_catbase_20251128.stp
3D_models/echoear catbase cover 2025-11-22.STEP
3D_models/echoear catbase ball only 2025-11-22.STEP
3D_models/echoear_catbase_platform_btm_20251128.stp
3D_models/echoear catbase platform top 2025-11-22.STEP

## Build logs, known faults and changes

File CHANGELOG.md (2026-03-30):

# ChangeLog

## V1.0.5 - 2026-03-30

* Refactor project layout to support multiple demo projects without branch switching.
* Add three independent demo projects under `software/`:
  * `esp_vocat_rotating_base_bell_event_detection`
  * `esp_vocat_rotating_base_iphone_detection`
  * `esp_vocat_rotating_base_magnetic_accessory_detection`
* Extract shared components to `software/common_components` and make all demo projects reuse them.
* Add profile-based compatibility for `magnetic_slide_switch` to support different event sets across demos (`base`, `bell`, `iphone`, `magnetic_accessory`).
* Update project CMake configuration and local dependency paths to match the new shared-component structure.
* Update root `README.md` and `README_CN.md` with new project structure and demo descriptions.
* Consolidate changelog management by removing per-project changelog files and keeping a single root `CHANGELOG.md`.

## V1.0.4 - 2026-01-15

* Optimize the BMM150 sampling rate.
* Optimize the single-click event detection logic of the magnetic sliding switch.

## V1.0.3 - 2025-12-24

* Add fish detached event and pairing cancelled event detection in magnetic slide switch component.
* Add initial position detection for magnetic slide switch on power-on.

## V1.0.2 - 2025-12-19

* Fix the sound source recognition angle control logic.
* Update the thresholds when using QMC6309 for the sliding switch.

## V1.0.1 - 2025-12-18

* Add feed-fish event and detection event for two bases approaching each other face-to-face (for pairing).
* Optimize single-click event detection logic.
* Optimize the automatic calibration program.
* Update README documentation.

## V1.0.0 - 2025-12-02

* First official release.
* Stepper motor control with acceleration/deceleration and predefined actions (shake head, look around, beat swing, cat nuzzle).
* Magnetic slide switch detection with auto-calibration (support Hall sensor, BMM150, QMC6309).
* UART communication protocol for angle control and event notification.
* Base auto-calibration with limit switch on startup.
* NVS storage for persistent calibration data.

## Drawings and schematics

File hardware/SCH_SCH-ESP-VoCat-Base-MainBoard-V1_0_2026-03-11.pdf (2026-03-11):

# Type C for debug and function expansion

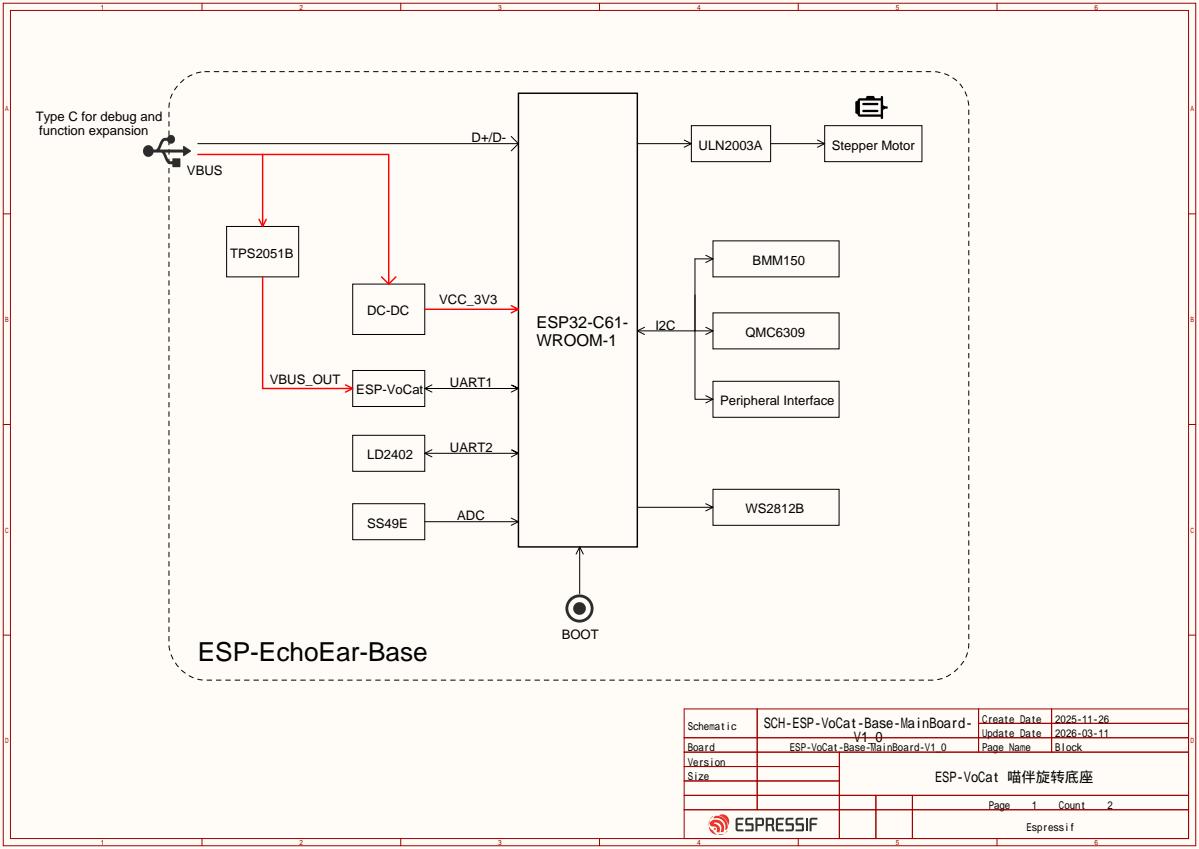
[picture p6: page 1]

Schematic | SCH-ESP-VoCat-Base-MainBoard-V1_0 | Create Date | 2025-11-26

Update Date | 2026-03-11

Board | ESP-VoCat-Base-MainBoard-V1_0 | Page Name | Block
Version | | ESP-VoCat 喵伴旋转底座
Size

Page 1 Count 2

Espressif

USB-C | DC-DC | ESP32-C61

# 500mA Current Limit

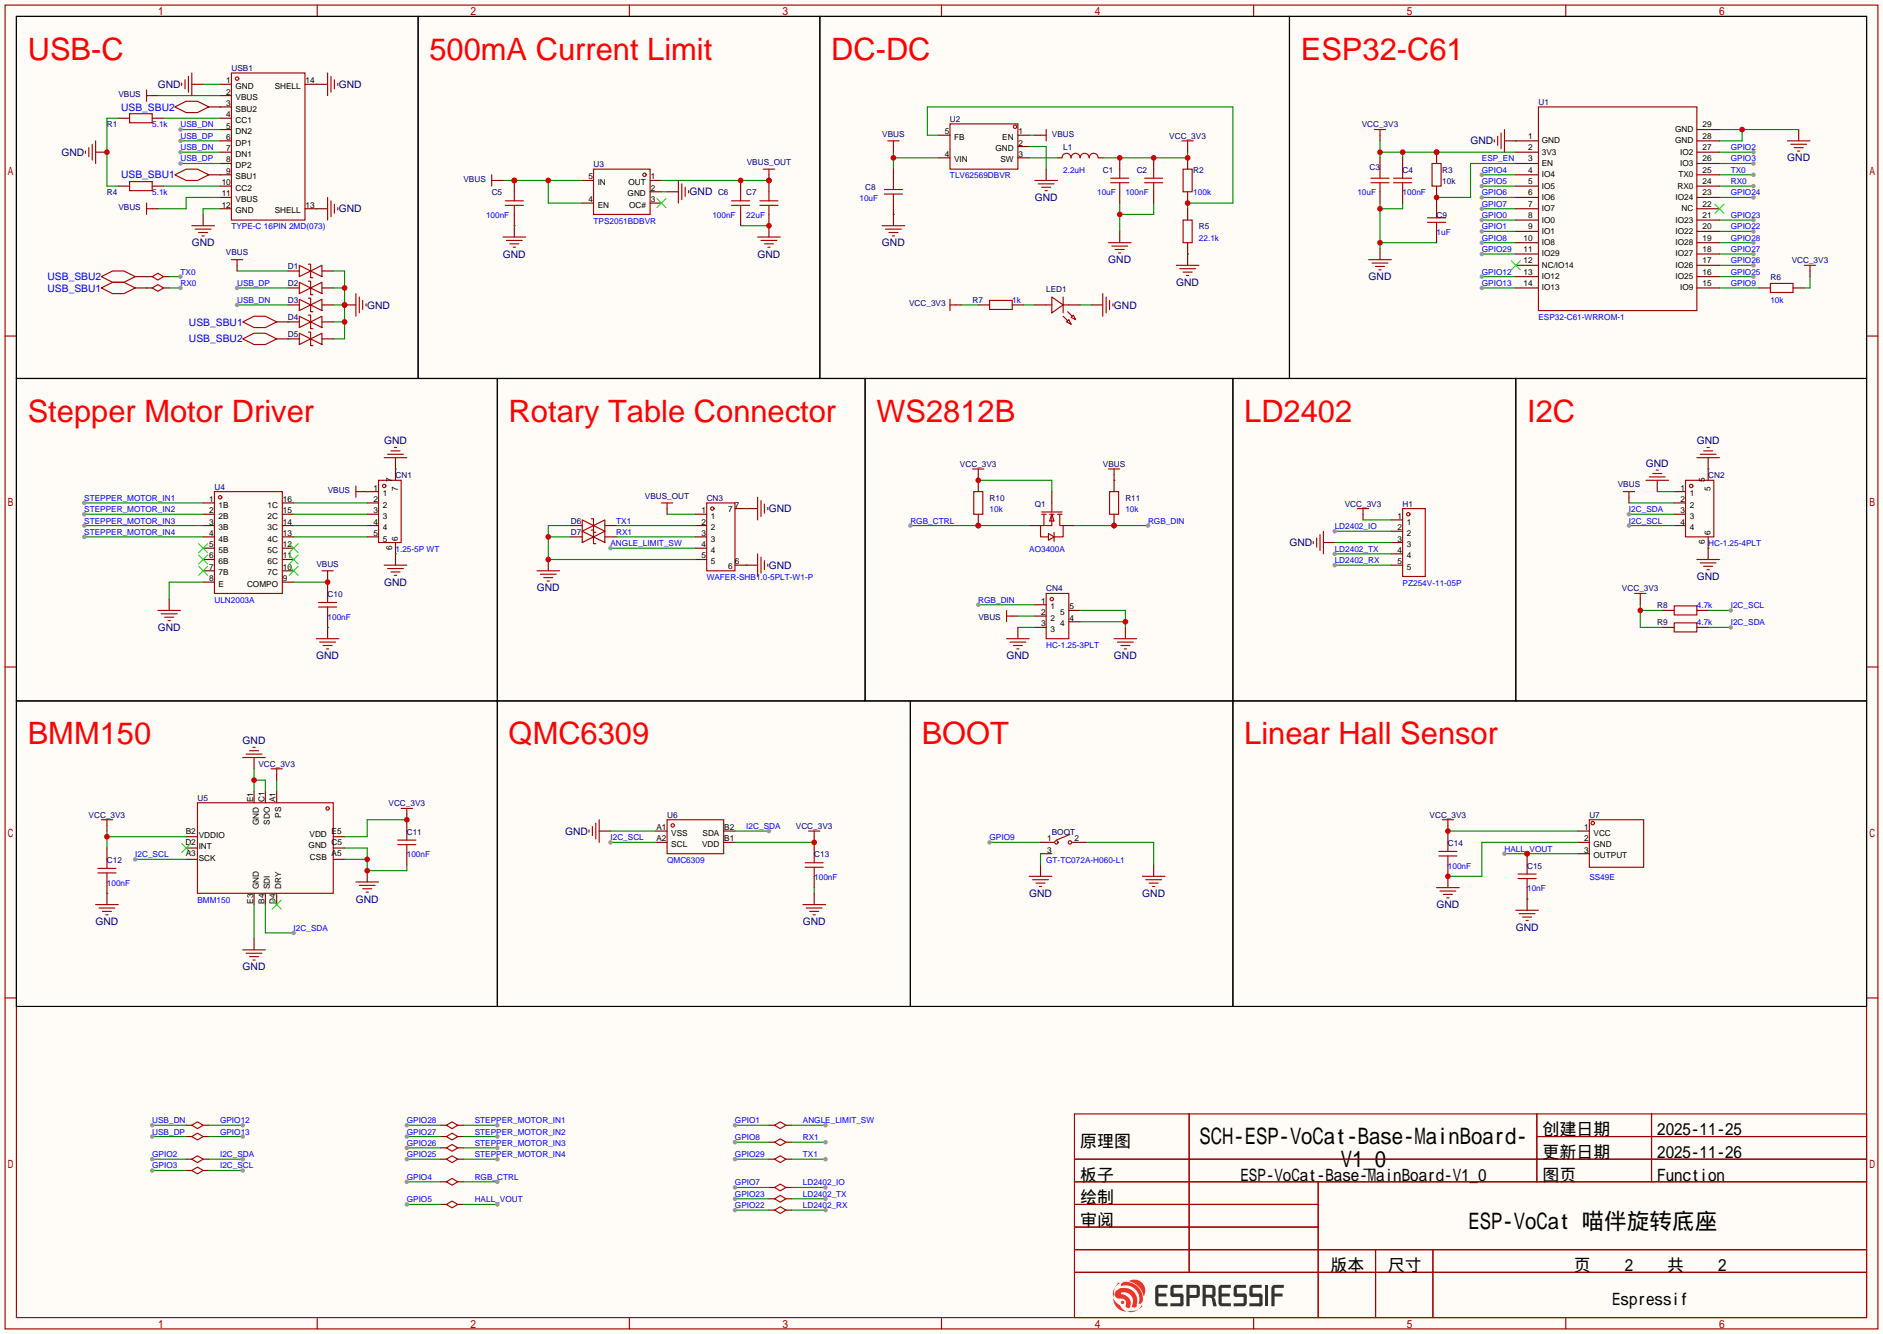
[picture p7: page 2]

原理图 | SCH-ESP-VoCat-Base-MainBoard-V1_0 | 创建日期 | 2025-11-25

更新日期 | 2025-11-26

板子 | ESP-VoCat-Base-MainBoard-V1_0 | 图页 | Function
绘制 | | ESP-VoCat 喵伴旋转底座
审阅

Espressif

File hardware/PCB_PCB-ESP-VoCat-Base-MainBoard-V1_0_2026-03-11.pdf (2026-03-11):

## BOOT

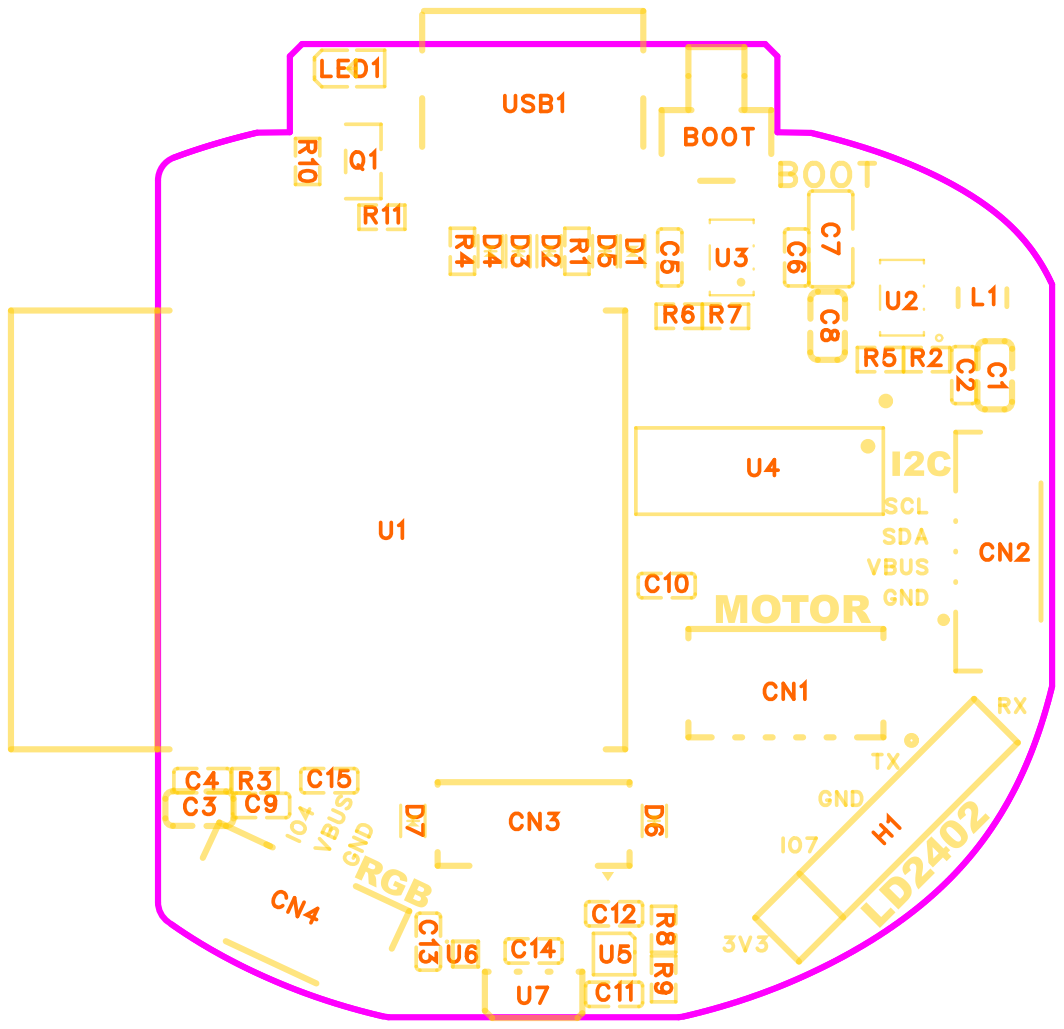
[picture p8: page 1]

## BOOT

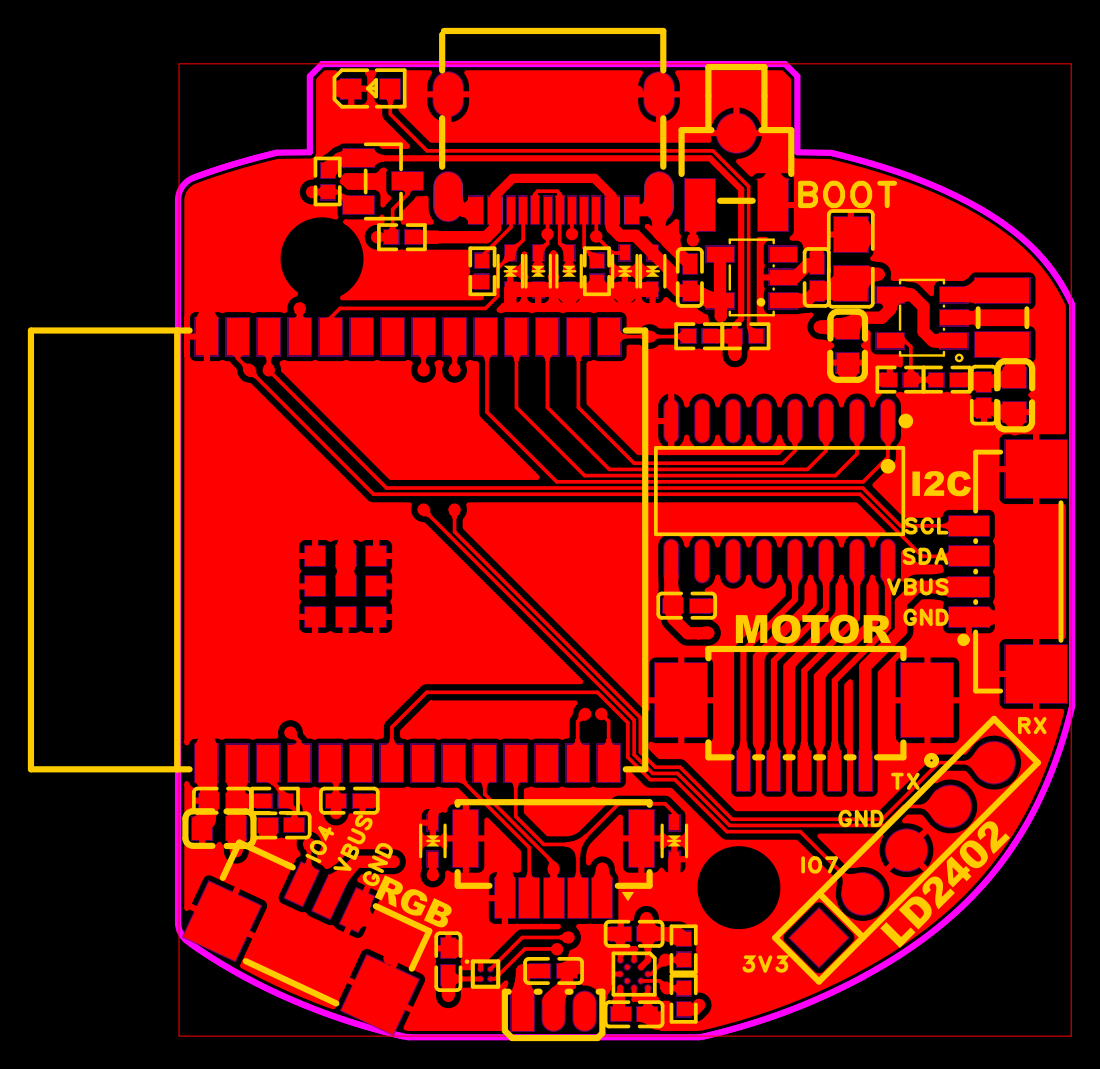
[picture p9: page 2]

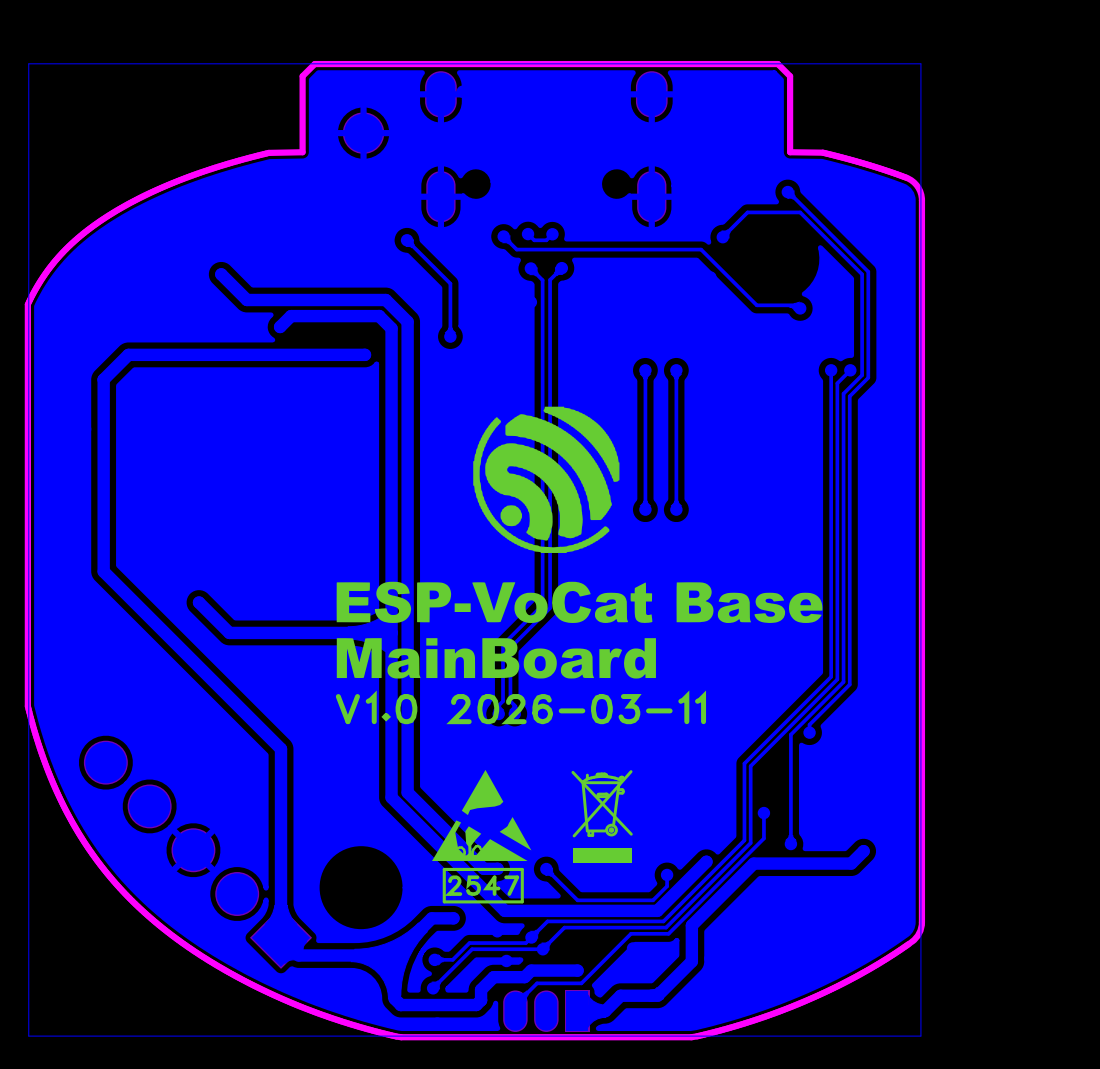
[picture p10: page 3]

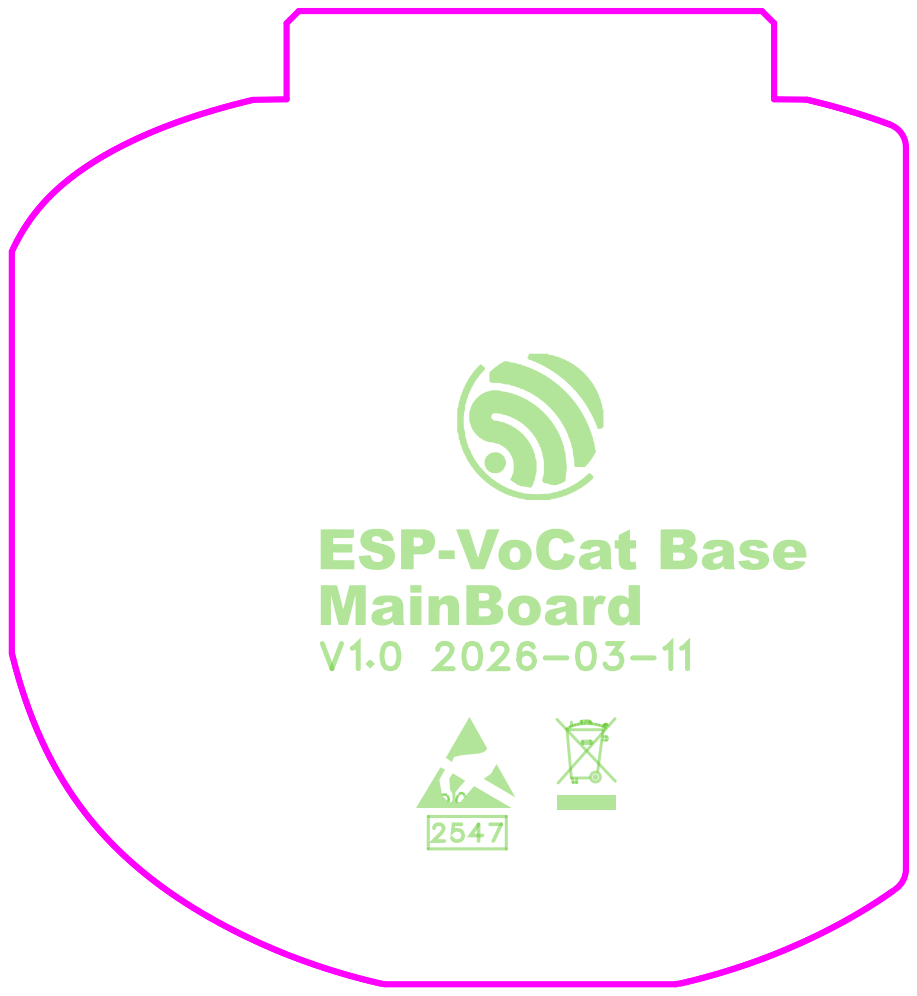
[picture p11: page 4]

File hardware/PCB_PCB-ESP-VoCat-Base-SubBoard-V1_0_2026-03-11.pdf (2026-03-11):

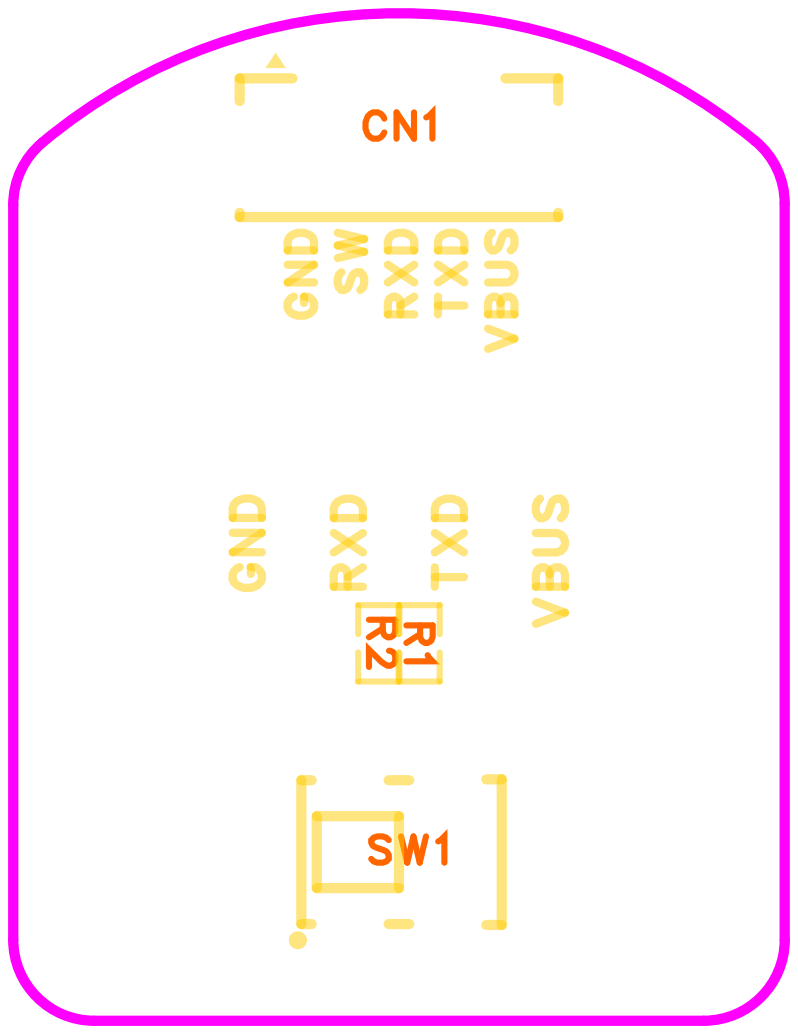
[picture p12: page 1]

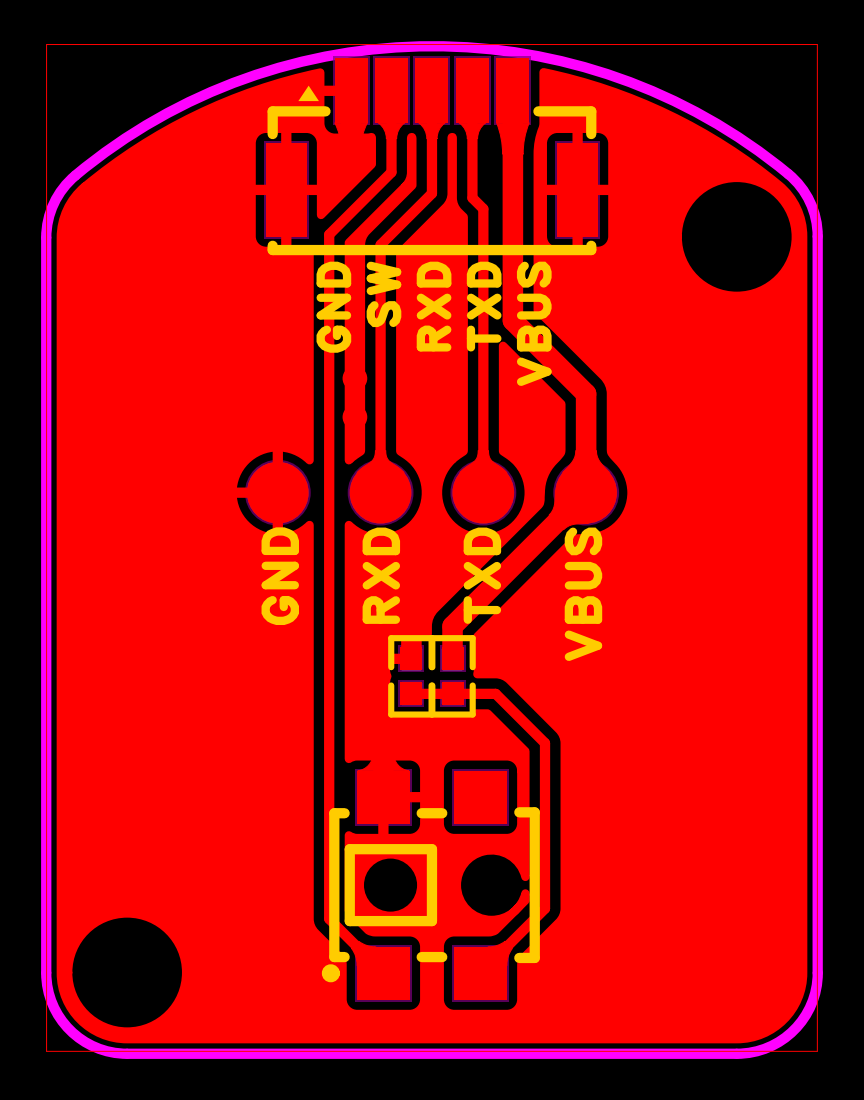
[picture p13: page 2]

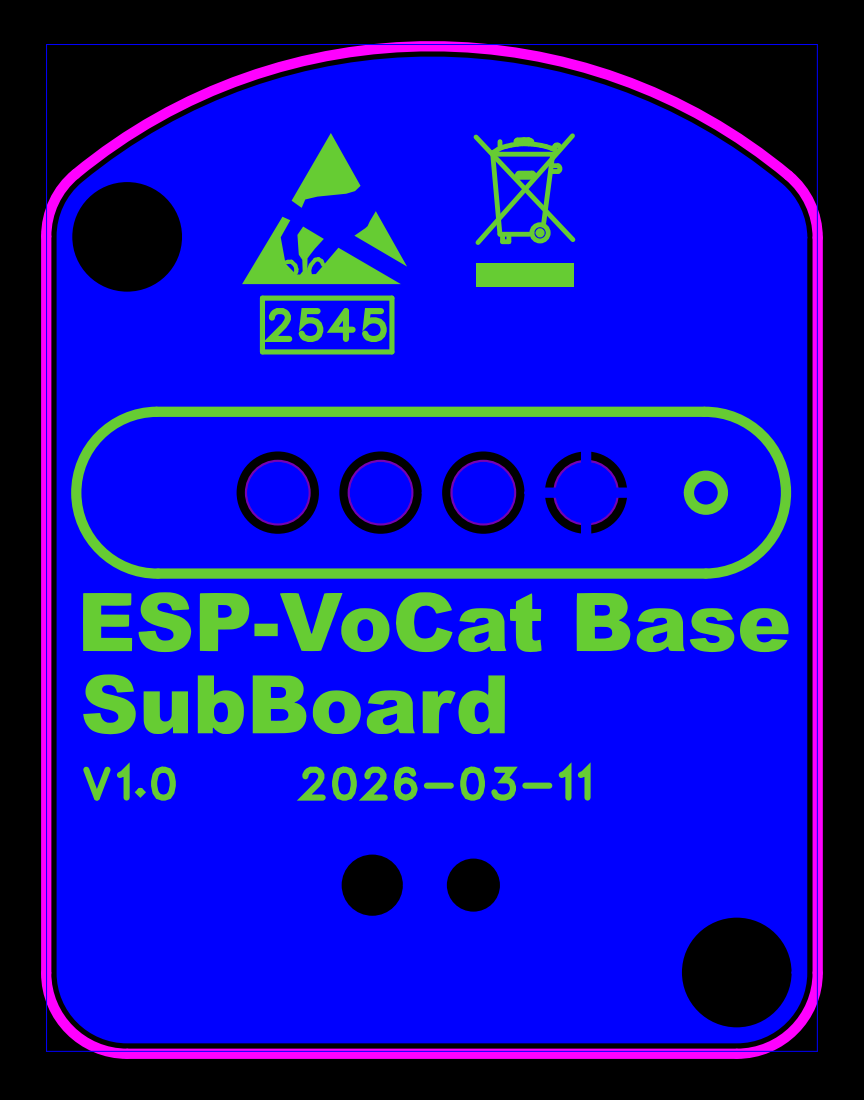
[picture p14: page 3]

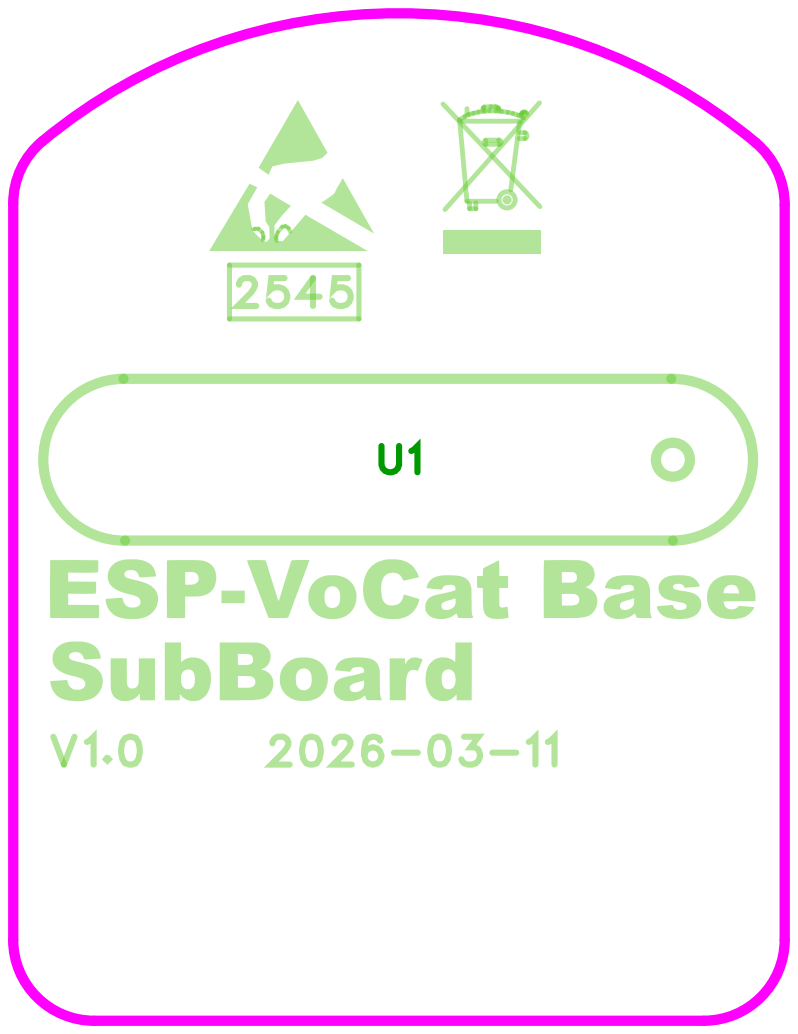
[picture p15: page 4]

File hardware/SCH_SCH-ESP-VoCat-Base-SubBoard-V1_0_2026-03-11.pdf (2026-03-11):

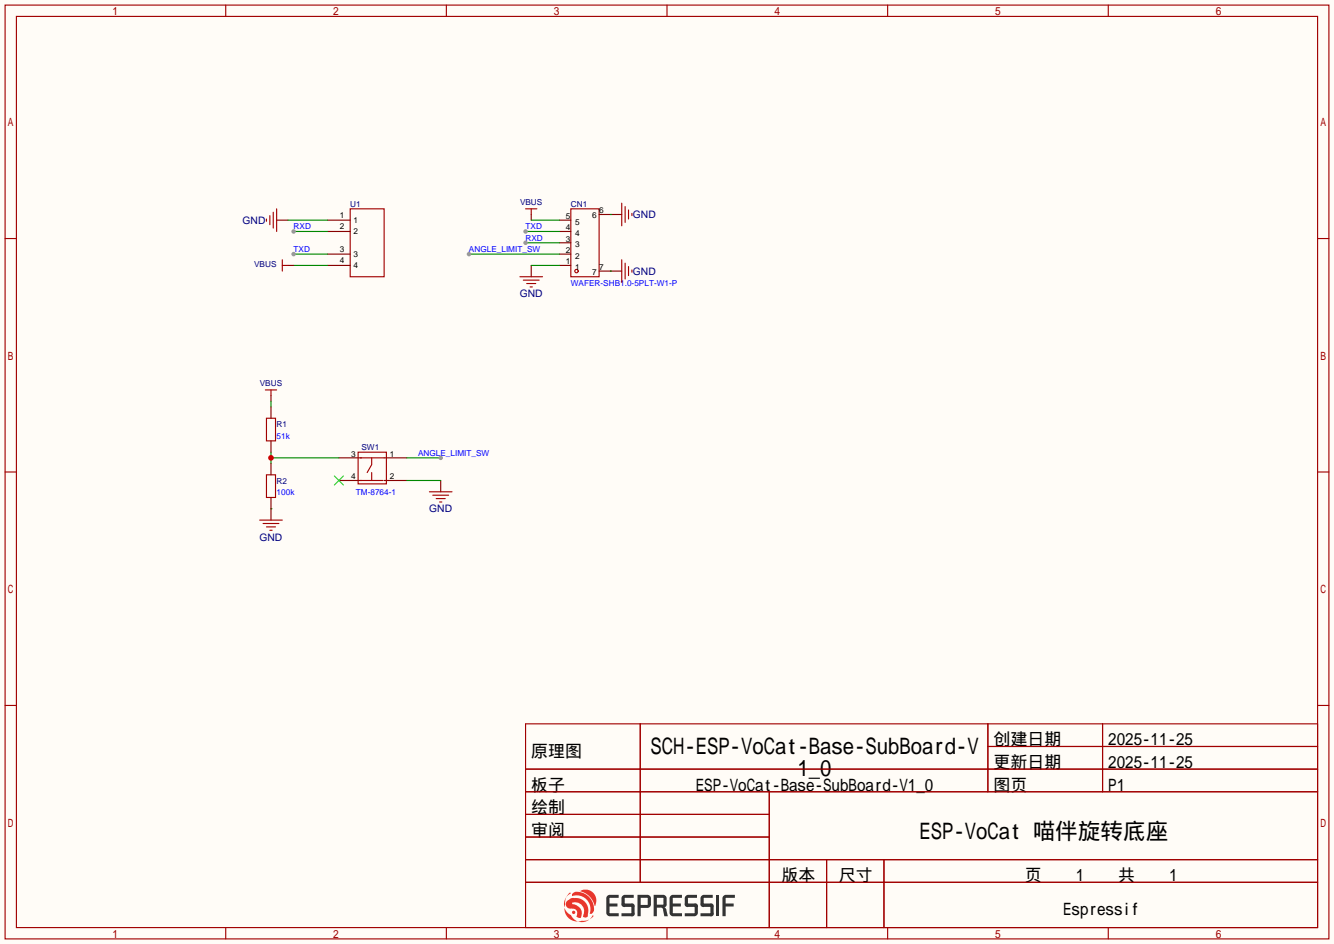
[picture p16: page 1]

原理图 | SCH-ESP-VoCat-Base-SubBoard-V 1_0 | 创建日期 | 2025-11-25

更新日期 | 2025-11-25

板子 | ESP-VoCat-Base-SubBoard-V1_0 | 图页 | P1
绘制 | | ESP-VoCat 喵伴旋转底座
审阅

Espressif

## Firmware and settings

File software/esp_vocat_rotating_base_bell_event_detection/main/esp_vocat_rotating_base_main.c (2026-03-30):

/*
 * SPDX-FileCopyrightText: 2024-2025 Espressif Systems (Shanghai) CO LTD
 *
 * SPDX-License-Identifier: Apache-2.0
 */

#include <stdio.h>
#include "freertos/FreeRTOS.h"
#include "freertos/task.h"
#include "freertos/semphr.h"
#include "driver/gpio.h"
#include "esp_log.h"
#include "esp_app_format.h"
#include "esp_ota_ops.h"
#include "iot_button.h"
#include "nvs_flash.h"
#include "control_serial.h"
#include "stepper_motor.h"
#include "magnetic_slide_switch.h"

static const char *TAG = "ESP_VoCat Rotating Base";

#define BASE_ANGLE_LIMIT_SWITCH_GPIO (GPIO_NUM_1)
#define BOOT_BUTTON_GPIO             (GPIO_NUM_9)
#define BASE_CALIBRATION_TASK_STACK_SIZE    (1024 * 3)

static SemaphoreHandle_t s_limit_switch_semaphore = NULL;

/**
 * @brief Base angle limit switch event callback function
 * 
 * @param arg Button handle
 * @param data Button event data
 */
static void base_angle_limit_switch_event_cb(void *arg, void *data)
{
    button_event_t event = iot_button_get_event(arg);
    if (event == BUTTON_PRESS_DOWN) {
        // Release semaphore to notify calibration task
        BaseType_t xHigherPriorityTaskWoken = pdFALSE;
        xSemaphoreGiveFromISR(s_limit_switch_semaphore, &xHigherPriorityTaskWoken);
        portYIELD_FROM_ISR(xHigherPriorityTaskWoken);
    }
}

/**
 * @brief Boot button event callback function
 * 
 * @param arg Button handle
 * @param data Button event data
 */
static void boot_button_event_cb(void *arg, void *data)
{
    button_event_t event = iot_button_get_event(arg);
    if (event == BUTTON_LONG_PRESS_START) {
        ESP_LOGI(TAG, "Boot button long press detected, starting recalibration...");
        magnetic_slide_switch_start_recalibration();
    }
}

/**
 * @brief Magnetic slide switch event callback function
 * 
 * @param event Detected magnetic slide switch event
 * 
 * @note This callback receives events from the magnetic slide switch and sends them via UART
 */
static void magnetic_slide_switch_event_cb(magnetic_slide_switch_event_t event)
{
    // Send event to serial port
    esp_err_t ret = control_serial_send_magnetic_switch_event((uint16_t)event);
    if (ret != ESP_OK) {
        ESP_LOGW(TAG, "Failed to send magnetic switch event: %d", event);
    }
}

/**
 * @brief Initialize base angle limit switch
 */
static void base_angle_limit_switch_init(void)
{
    button_handle_t btn = NULL;

    button_config_t cfg = {
        .type = BUTTON_TYPE_GPIO,
        .long_press_time = CONFIG_BUTTON_LONG_PRESS_TIME_MS,
        .short_press_time = CONFIG_BUTTON_SHORT_PRESS_TIME_MS,
        .gpio_button_config = {
            .gpio_num = BASE_ANGLE_LIMIT_SWITCH_GPIO,
            .active_level = 0,
        },
    };
    btn = iot_button_create(&cfg);
    assert(btn != NULL);
    iot_button_register_cb(btn, BUTTON_PRESS_DOWN, base_angle_limit_switch_event_cb, NULL);
    iot_button_register_cb(btn, BUTTON_PRESS_UP, base_angle_limit_switch_event_cb, NULL);
}

/**
 * @brief Initialize boot button
 */
static void boot_button_init(void)
{
    button_handle_t boot_btn = NULL;

    button_config_t boot_cfg = {
        .type = BUTTON_TYPE_GPIO,
        .long_press_time = CONFIG_BUTTON_LONG_PRESS_TIME_MS,  // Use default long press time (usually 5000ms)
        .short_press_time = CONFIG_BUTTON_SHORT_PRESS_TIME_MS,
        .gpio_button_config = {
            .gpio_num = BOOT_BUTTON_GPIO,
            .active_level = 0,  // Active low
        },
    };
    boot_btn = iot_button_create(&boot_cfg);
    assert(boot_btn != NULL);
    iot_button_register_cb(boot_btn, BUTTON_LONG_PRESS_START, boot_button_event_cb, NULL);
    
    ESP_LOGI(TAG, "Boot button initialized on GPIO%d (long press to recalibrate)", BOOT_BUTTON_GPIO);
}

/**
 * @brief Base calibration task
 * 
 * @param arg Task parameter (unused)
 * 
 * @note Rotates motor until limit switch is pressed, then moves to home position
 * @note If limit switch is not pressed within 2 seconds (mechanical fault protection),
 *       directly rotates 95 degrees to the right to reach home position
 */
static void base_calibration_task(void *arg)
{
    ESP_LOGI(TAG, "Base calibration task started");
    base_angle_limit_switch_init();

    // Record start time for timeout detection
    TickType_t start_time = xTaskGetTickCount();
    const TickType_t timeout_ticks = pdMS_TO_TICKS(2000);  // 2 seconds timeout

    while (1) {
        // Check if timeout has occurred
        TickType_t elapsed_time = xTaskGetTickCount() - start_time;
        if (elapsed_time >= timeout_ticks) {
            ESP_LOGW(TAG, "Calibration timeout! Limit switch not pressed within 2 seconds");
            ESP_LOGW(TAG, "Assuming mechanical fault, moving directly to home position");
            vTaskDelay(pdMS_TO_TICKS(200));
            stepper_rotate_angle_with_accel(95.0, STEPPER_SPEED_FAST);
            stepper_motor_power_off();
            ESP_LOGI(TAG, "Base calibration completed (timeout fallback mode)");
            vTaskDelete(NULL);
        }

        // Try to take semaphore with no wait
        if (xSemaphoreTake(s_limit_switch_semaphore, 0) == pdTRUE) {
            // Limit switch pressed, move to home position
            ESP_LOGI(TAG, "Limit switch pressed, moving to home position");
            vTaskDelay(pdMS_TO_TICKS(200));
            stepper_rotate_angle_with_accel(95.0, STEPPER_SPEED_FAST);
            stepper_motor_power_off();
            ESP_LOGI(TAG, "Base calibration completed");
            vTaskDelete(NULL);
        } else {
            // Continue rotating
            stepper_rotate_angle_with_accel(-5.0, STEPPER_SPEED_FAST);
            vTaskDelay(pdMS_TO_TICKS(2));
        }
    }
}

void app_main(void)
{
    // Initialize NVS (for saving calibration data)
    esp_err_t ret = nvs_flash_init();
    if (ret == ESP_ERR_NVS_NO_FREE_PAGES || ret == ESP_ERR_NVS_NEW_VERSION_FOUND) {
        // NVS partition is full or version mismatch, erase and reinitialize
        ESP_ERROR_CHECK(nvs_flash_erase());
        ret = nvs_flash_init();
    }
    ESP_ERROR_CHECK(ret);
    ESP_LOGI(TAG, "NVS initialized");
    
    // Create binary semaphore for limit switch notification
    s_limit_switch_semaphore = xSemaphoreCreateBinary();
    if (s_limit_switch_semaphore == NULL) {
        ESP_LOGE(TAG, "Failed to create limit switch semaphore");
        return;
    }
    
    stepper_motor_gpio_init();
    base_angle_limit_switch_init();
    boot_button_init();  // Initialize Boot button
    control_serial_init();
    control_serial_start_magnetic_detect_task();

    // Register magnetic slide switch event callback before starting the switch
    ret = magnetic_slide_switch_register_callback(magnetic_slide_switch_event_cb);
    if (ret != ESP_OK) {
        ESP_LOGE(TAG, "Failed to register magnetic slide switch callback: %s", esp_err_to_name(ret));
    } else {
        ESP_LOGI(TAG, "Magnetic slide switch event callback registered");
    }

    xTaskCreate(base_calibration_task, "base_calibration_task", BASE_CALIBRATION_TASK_STACK_SIZE, NULL, 10, NULL);
    magnetic_slide_switch_start();
}

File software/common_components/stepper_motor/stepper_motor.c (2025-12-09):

/*
 * SPDX-FileCopyrightText: 2024-2025 Espressif Systems (Shanghai) CO LTD
 *
 * SPDX-License-Identifier: Apache-2.0
 */

#include <stdio.h>
#include "freertos/FreeRTOS.h"
#include "freertos/task.h"
#include "driver/gpio.h"
#include "esp_log.h"
#include "esp_rom_sys.h"
#include "esp_random.h"
#include "stepper_motor.h"

static const char *TAG = "Stepper Motor";

/* ========== Step Sequence Definitions ========== */

/**
 * @brief 8-beat half-step sequence - Clockwise (forward rotation)
 * @note Alternates single-phase and dual-phase excitation for smoother motion and higher precision
 */
static const int step_sequence_cw[8][4] = {
    {1, 0, 0, 0},  // Step 1: IN1 (single phase)
    {1, 1, 0, 0},  // Step 2: IN1+IN2 (dual phase)
    {0, 1, 0, 0},  // Step 3: IN2 (single phase)
    {0, 1, 1, 0},  // Step 4: IN2+IN3 (dual phase)
    {0, 0, 1, 0},  // Step 5: IN3 (single phase)
    {0, 0, 1, 1},  // Step 6: IN3+IN4 (dual phase)
    {0, 0, 0, 1},  // Step 7: IN4 (single phase)
    {1, 0, 0, 1}   // Step 8: IN4+IN1 (dual phase)
};

/**
 * @brief 8-beat half-step sequence - Counterclockwise (reverse rotation)
 * @note Alternates single-phase and dual-phase excitation for smoother motion and higher precision
 */
static const int step_sequence_ccw[8][4] = {
    {1, 0, 0, 1},  // Step 1: IN4+IN1 (dual phase)
    {0, 0, 0, 1},  // Step 2: IN4 (single phase)
    {0, 0, 1, 1},  // Step 3: IN3+IN4 (dual phase)
    {0, 0, 1, 0},  // Step 4: IN3 (single phase)
    {0, 1, 1, 0},  // Step 5: IN2+IN3 (dual phase)
    {0, 1, 0, 0},  // Step 6: IN2 (single phase)
    {1, 1, 0, 0},  // Step 7: IN1+IN2 (dual phase)
    {1, 0, 0, 0}   // Step 8: IN1 (single phase)
};

/* ========== Private Functions ========== */

/**
 * @brief Set stepper motor pin states
 * 
 * @param in1 IN1 pin state (0 or 1)
 * @param in2 IN2 pin state (0 or 1)
 * @param in3 IN3 pin state (0 or 1)
 * @param in4 IN4 pin state (0 or 1)
 */
static void set_motor_pins(int in1, int in2, int in3, int in4)
{
    gpio_set_level(IN1_PIN, in1);
    gpio_set_level(IN2_PIN, in2);
    gpio_set_level(IN3_PIN, in3);
    gpio_set_level(IN4_PIN, in4);
}

/**
 * @brief Stepper motor clockwise one step
 * 
 * @param step Current step number (will be auto modulo 8)
 */
static void stepper_step_cw(int step)
{
    step = step % 8;  // Ensure step is in range 0-7 (8 steps in half-step mode)
    set_motor_pins(step_sequence_cw[step][0], 
                   step_sequence_cw[step][1], 
                   step_sequence_cw[step][2], 
                   step_sequence_cw[step][3]);
}

/**
 * @brief Stepper motor counterclockwise one step
 * 
 * @param step Current step number (will be auto modulo 8)
 */
static void stepper_step_ccw(int step)
{
    step = step % 8;  // Ensure step is in range 0-7 (8 steps in half-step mode)
    set_motor_pins(step_sequence_ccw[step][0], 
                   step_sequence_ccw[step][1], 
                   step_sequence_ccw[step][2], 
                   step_sequence_ccw[step][3]);
}

/**
 * @brief Microsecond precision delay function
 * 
 * @param delay_us Delay time (microseconds)
 */
static inline void precise_delay_us(int delay_us)
{
    if (delay_us > 0) {
        esp_rom_delay_us(delay_us);
    }
}

/* ========== Public Function Implementations ========== */

/**
 * @brief Clockwise rotation with acceleration/deceleration
 * 
 * @param steps Number of rotation steps
 * @param target_delay_us Target speed delay (microseconds)
 * 
 * @note Uses linear acceleration/deceleration algorithm, divided into acceleration, constant speed, and deceleration phases
 */
static void stepper_rotate_cw_with_accel(int steps, int target_delay_us)
{
    int start_delay_us = STEPPER_START_DELAY_US;
    int accel_steps = STEPPER_ACCEL_STEPS;
    int decel_steps = STEPPER_DECEL_STEPS;
    
    // If total steps too few, adjust acceleration/deceleration steps
    if (steps < (accel_steps + decel_steps)) {
        accel_steps = steps / 3;
        decel_steps = steps / 3;
    }
    
    int constant_steps = steps - accel_steps - decel_steps;
    int current_delay_us;
    
    ESP_LOGD(TAG, "Accel-Decel profile: accel=%d, constant=%d, decel=%d steps", 
             accel_steps, constant_steps, decel_steps);
    
    // Acceleration phase
    for (int i = 0; i < accel_steps; i++) {
        // Linear interpolation: gradually decrease from start_delay to target_delay
        current_delay_us = start_delay_us - (start_delay_us - target_delay_us) * i / accel_steps;
        stepper_step_cw(i);
        precise_delay_us(current_delay_us);
    }
    
    // Constant speed phase
    for (int i = accel_steps; i < accel_steps + constant_steps; i++) {
        stepper_step_cw(i);
        precise_delay_us(target_delay_us);
    }
    
    // Deceleration phase
    for (int i = accel_steps + constant_steps; i < steps; i++) {
        // Linear interpolation: gradually increase from target_delay to start_delay
        int decel_progress = i - (accel_steps + constant_steps);
        current_delay_us = target_delay_us + (start_delay_us - target_delay_us) * decel_progress / decel_steps;
        stepper_step_cw(i);
        precise_delay_us(current_delay_us);
    }
}

/**
 * @brief Counterclockwise rotation with acceleration/deceleration
 * 
 * @param steps Number of rotation steps
 * @param target_delay_us Target speed delay (microseconds)
 * 
 * @note Uses linear acceleration/deceleration algorithm, divided into acceleration, constant speed, and deceleration phases
 */
static void stepper_rotate_ccw_with_accel(int steps, int target_delay_us)
{
    int start_delay_us = STEPPER_START_DELAY_US;
    int accel_steps = STEPPER_ACCEL_STEPS;
    int decel_steps = STEPPER_DECEL_STEPS;
    
    // If total steps too few, adjust acceleration/deceleration steps
    if (steps < (accel_steps + decel_steps)) {
        accel_steps = steps / 3;
        decel_steps = steps / 3;
    }
    
    int constant_steps = steps - accel_steps - decel_steps;
    int current_delay_us;
    
    ESP_LOGD(TAG, "Accel-Decel profile: accel=%d, constant=%d, decel=%d steps", 
             accel_steps, constant_steps, decel_steps);
    
    // Acceleration phase
    for (int i = 0; i < accel_steps; i++) {
        current_delay_us = start_delay_us - (start_delay_us - target_delay_us) * i / accel_steps;
        stepper_step_ccw(i);
        precise_delay_us(current_delay_us);
    }
    
    // Constant speed phase
    for (int i = accel_steps; i < accel_steps + constant_steps; i++) {
        stepper_step_ccw(i);
        precise_delay_us(target_delay_us);
    }
    
    // Deceleration phase
    for (int i = accel_steps + constant_steps; i < steps; i++) {
        int decel_progress = i - (accel_steps + constant_steps);
        current_delay_us = target_delay_us + (start_delay_us - target_delay_us) * decel_progress / decel_steps;
        stepper_step_ccw(i);
        precise_delay_us(current_delay_us);
    }
}
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

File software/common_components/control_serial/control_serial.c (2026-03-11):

/*
 * SPDX-FileCopyrightText: 2024-2025 Espressif Systems (Shanghai) CO LTD
 *
 * SPDX-License-Identifier: Apache-2.0
 */

#include <stdio.h>
#include "freertos/FreeRTOS.h"
#include "freertos/task.h"
#include "driver/gpio.h"
#include "driver/uart.h"
#include "esp_log.h"
#include "stepper_motor.h"
#include "control_serial.h"
#include "magnetic_slide_switch.h"

static const char *TAG = "Control Serial";

/**
 * @brief UART command receive task
 * 
 * @param arg Task parameter (unused)
 * 
 * @note This task loops to receive UART data, parse commands and execute corresponding operations:
 *       - CMD_BASE_ANGLE_CONTROL: Control base rotation to specified angle
 *       - CMD_BASE_ACTION_CONTROL: Execute predefined actions
 *       - CMD_MAGNETIC_SWITCH_EVENT: Magnetic switch calibration command
 * @note Implements frame header synchronization to handle data misalignment
 */
static void uart_cmd_receive_task(void *arg)
{
    // Track absolute angle of the base (0-180 degrees, initial: 90 degrees)
    static float s_base_absolute_angle = 90.0f;
    
    // Configure temporary buffer for incoming data
    uint8_t *data = (uint8_t *) malloc(BUF_SIZE);
    if (data == NULL) {
        ESP_LOGE(TAG, "Failed to allocate UART buffer");
        vTaskDelete(NULL);
        return;
    }

    while (1) {
        // Read data from UART
        int len = uart_read_bytes(ECHO_UART_PORT_NUM, data, (BUF_SIZE - 1), 20 / portTICK_PERIOD_MS);
        if (len > 0) {
            // Frame header synchronization: search for 0xAA 0x55
            int frame_start = -1;
            for (int i = 0; i < len - 1; i++) {
                if (data[i] == UART_FRAME_HEAD_H && data[i + 1] == UART_FRAME_HEAD_L) {
                    frame_start = i;
                    break;
                }
            }
            
            // If frame header not found, discard data and continue
            if (frame_start == -1) {
                ESP_LOGD(TAG, "Frame header not found in %d bytes, discarding", len);
                continue;
            }
            
            // If frame header not at beginning, log warning
            if (frame_start > 0) {
                ESP_LOGW(TAG, "Frame header found at offset %d, discarded %d bytes", frame_start, frame_start);
            }
            
            // Check if we have enough data for minimum frame
            int remaining_len = len - frame_start;
            if (remaining_len < UART_FRAME_MIN_LEN) {
                ESP_LOGW(TAG, "Incomplete frame: only %d bytes after header", remaining_len);
                continue;
            }
            
            // Point to the start of the frame
            uint8_t *frame = data + frame_start;
            
            // Get data length from frame
            uint16_t data_len = (frame[2] << 8) | frame[3];
            
            // Validate data length
            if (data_len == 0 || data_len > BUF_SIZE - UART_FRAME_HEADER_LEN - 1) {
                ESP_LOGW(TAG, "Invalid data length: %d", data_len);
                continue;
            }
            
            // Check if we have complete frame
            int expected_frame_len = UART_FRAME_HEADER_LEN + data_len + 1; // header + data + checksum
            if (remaining_len < expected_frame_len) {
                ESP_LOGW(TAG, "Incomplete frame: expected %d bytes, got %d", expected_frame_len, remaining_len);
                continue;
            }
            
            // Get command code and data length
            uint8_t cmd = frame[4];
            
            // Calculate checksum for the entire data payload (command code + data bytes)
            uint8_t calc_checksum = 0;
            for (int i = 4; i < 4 + data_len; i++) {
                calc_checksum += frame[i];
            }
            
            // Get received checksum (last byte of frame)
            uint8_t received_checksum = frame[4 + data_len];
            
            // Verify checksum FIRST before parsing any data
            if (calc_checksum != received_checksum) {
                ESP_LOGW(TAG, "Checksum verification failed: calc=0x%02X, recv=0x%02X, cmd=0x%02X", 
                         calc_checksum, received_checksum, cmd);
                continue;  // Discard this frame and continue
            }
            
            // Checksum verified, now safe to parse and execute commands
            
            // Parse data according to command type
            if (cmd == CMD_BASE_ANGLE_CONTROL) {  // Base angle control
                if (data_len != 3) {  // Should be: cmd(1) + angle(2) = 3 bytes
                    ESP_LOGW(TAG, "Invalid data length for angle control: %d (expected 3)", data_len);
                    continue;
                }
                
                // Get data value (combine two bytes) - sound source angle from head (0-180 degrees)
                // Value is relative to initial position (90 degrees = facing head directly)
                uint16_t value = (frame[5] << 8) | frame[6];
                
                // Check if received angle is within valid range (0-180 degrees)
                if (value > 180) {
                    ESP_LOGW(TAG, "Received angle %d out of range [0, 180], ignoring rotation. Current absolute angle: %.1f", 
                             value, s_base_absolute_angle);
                    continue;
                }
                
                // Calculate rotation angle relative to initial position (90 degrees)
                // diff_angle = value - 90 means:
                //   - value = 90: diff_angle = 0 (no rotation, facing head)
                //   - value = 120: diff_angle = 30 (rotate right 30 degrees)
                //   - value = 60: diff_angle = -30 (rotate left 30 degrees)
                float diff_angle = (float)value - 90.0f;
                
                // Calculate new absolute angle after rotation
                float new_absolute_angle = s_base_absolute_angle + diff_angle;
                
                // Check if new absolute angle would be out of range (0-180 degrees)
                if (new_absolute_angle < 0.0f || new_absolute_angle > 180.0f) {
                    ESP_LOGW(TAG, "Rotation would result in angle %.1f out of range [0, 180], ignoring. Current: %.1f, received: %d, diff: %.1f", 
                             new_absolute_angle, s_base_absolute_angle, value, diff_angle);
                    continue;
                }
                
                ESP_LOGI(TAG, "Received sound source angle: %d, current absolute angle: %.1f, diff_angle: %.1f, new absolute angle: %.1f", 
                         value, s_base_absolute_angle, diff_angle, new_absolute_angle);
                
                // Execute angle control (rotate by diff_angle degrees)
                stepper_rotate_angle_with_accel((int16_t)diff_angle, STEPPER_SPEED_ULTRA_FAST);
                vTaskDelay(pdMS_TO_TICKS(100));
                stepper_motor_power_off();
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

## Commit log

2025-12-09 feat: add echoear_rotating_base example
    add echoear_rotating_base example
    add 3D files
    add hardware files
    add README files
    [EchoEar_catbase_20251128.stp, echoear catbase ball only 2025-11-22.STEP, echoear catbase cover 2025-11-22.STEP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]
2025-12-18 feat: update magnetic_slide_switch component
2025-12-19 fix: Fix the sound source recognition angle control logic
    [control_serial.c, magnetic_slide_switch.h]
2025-12-24 feat: update mag_slide_switch
    Add fish detached event and pairing cancelled event detection in magnetic slide switch component.
    Add initial position detection for magnetic slide switch on power-on.
2026-01-15 feat: Optimize the BMM150 sampling rate
    Optimize the single-click event detection logic of the magnetic sliding switch
2026-01-15 fix: fix uart
2026-03-11 feat: rename
    [VoCat_catbase_20251128.stp, vocat catbase ball only 2025-11-22.STEP, vocat catbase cover 2025-11-22.STEP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]
2026-03-11 feat: rename2
    [ESP-VoCat catbase ball only 2025-11-22.STEP, ESP-VoCat catbase cover 2025-11-22.STEP, ESP-VoCat catbase platform top 2025-11-22.STEP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]
2026-03-30 docs: add Magnetic Sensing Interaction Solution docs
2026-04-02 Fix: conflix event in calibration and phone detect
    [control_serial.h]
2026-04-16 Set target esp32c6
